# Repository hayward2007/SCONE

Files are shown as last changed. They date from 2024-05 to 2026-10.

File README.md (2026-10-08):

# SCONE

**도움이 필요한 사람에게 직접 찾아가는 로봇을 만들고 싶었습니다.**<br>
**Building a robot that can bring help to the person who needs it.**

Six-legged robot Capable Of rotational motioN · 김형석 / Hyoung-Seok Kim

[한국어](#한국어) · [English](#english) · [Posters & papers](#posters-and-papers) · [Videos](#videos) · [Development archive](#development-archive)

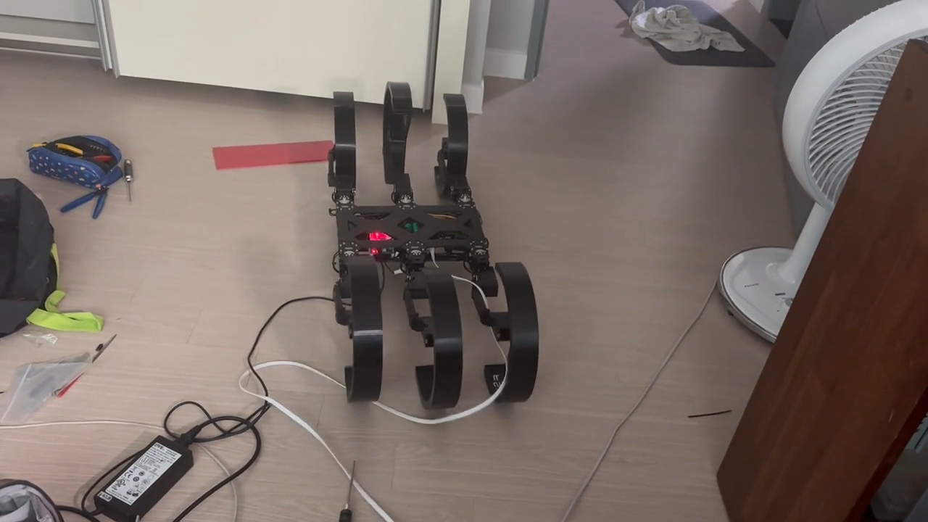
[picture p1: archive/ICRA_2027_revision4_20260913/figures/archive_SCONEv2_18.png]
SCONE v2 실물 로봇 / Physical SCONE v2 prototype


*SCONE v2의 실제 제작·동작 기록에서 가져온 장면입니다. / A frame from the original SCONE v2 hardware footage.*

> **보관된 프로젝트 / Archived project · 2026-10-09**<br>
> 제작 과정, 소스, 포스터, 논문, 실물 영상과 후속 설계를 함께 보존합니다.<br>
> Hardware history, source code, posters, papers, videos and later designs are preserved here.<br>
> [전체 정리 및 복원 안내 / Project closeout and restoration](docs/31-project-archive.md)

## 한국어

### 왜 만들었는가

고등학교에서 동아리를 홍보하던 중 친구가 쓰러진 일이 있었습니다.
그 일을 겪으며, 의식을 잃은 사람을 혼자 힘으로 옮기는 일이 얼마나 어려운지 실감했습니다.
도움이 필요한 사람에게 필요한 장비가 직접 찾아갈 수 있다면 어떨까 하는 생각이 들었습니다.

그 경험이 SCONE을 만들기 시작한 계기였습니다. 사람에게 직접 도달할 수 있는 이동 로봇을 만들고,
그 로봇을 **자동제세동기(AED)를 환자에게 전달하는 로봇으로 응용해 보았습니다.**
그 과정에서 중요하게 생각한 것은 평지에서 움직이는 것뿐 아니라, 실제 이동 경로에서 마주치는
계단과 턱도 통과할 수 있는 구조였습니다.

이 질문은 친환경 배송과 응급 장비 전달이라는 두 응용으로 이어졌습니다.
초기 논문과 포스터에는 배송 로봇의 이동 문제, 제작 과정, 실패와 개선을 정리했고,
포스터의 마지막에는 AED 같은 중요한 물품을 필요한 사람에게 직접 전달하는 방향을 담았습니다.
이 저장소는 그 생각이 실제 로봇, 실험, 설계와 코드로 발전한 기록입니다.

### 어떤 로봇인가

SCONE은 다리 끝에 **C자형 부채꼴 바퀴**를 붙인 6족 로봇입니다.
같은 말단 구조를 회전시키거나 다리 관절을 움직여 걷기, 구르기와 계단 이동을 탐구했습니다.
초기 실물은 3D 프린팅 프레임과 DYNAMIXEL 모터로 제작했고, 이후에는 MuJoCo에서 접촉 기하,
보행 제어와 계단 자세를 비교하며 동작을 분석했습니다.

이 저장소에는 다음 작업이 함께 들어 있습니다.

- **실물 제작:** 초기 평행 링크 구조, 프레임·타이어·모터·전원 개선과 v1/v2 동작 영상.
- **이동 제어:** Walk/Drive/Climb, 교대 삼각보, 연속 굴림과 다리별 굴림·보행 역할 분리.
- **시뮬레이션과 학습:** MuJoCo 모델, 지형 생성, PPO 학습, 다리 상실 대응과 반복 벤치마크.
- **후속 설계:** MARC 계열의 4족 기구, 하우징, 팔, Jetson·U2D2 배치 및 전원 검토.

자료에는 성공한 동작과 함께 전원 부족, 미끄러짐, 모터 과부하, 프레임 문제와 실패한 실험도 남겼습니다.
실물 제작 영상과 후속 시뮬레이션의 정량 실험은 각각의 조건과 근거를 따라 읽을 수 있도록 구분했습니다.

## English

### Why I built it

The idea began when a friend collapsed while I was promoting a club at my high school.
That experience made me realize how difficult it can be for one person to move someone who has lost consciousness.
I began thinking about a robot that could bring essential equipment directly to the person who needed it.

That became the starting point for SCONE. I wanted to build a mobile robot that could reach people,
and I explored **delivering an automated external defibrillator (AED) as an application.**
The mobility problem mattered: reaching a person could mean dealing with stairs and curbs as well as a flat floor.

The project connected that motivation with two applications: environmentally friendly delivery and emergency equipment delivery.
The original papers and poster document the delivery problem, construction, failures and improvements.
The poster also presents bringing vital supplies such as an AED directly to the recipient as a future application.
This repository preserves how that idea developed into hardware, experiments, designs and software.

### What SCONE is

SCONE is a six-legged robot with **C-shaped arc wheels at the ends of its limbs**.
By rotating the terminal frames and articulating the legs, I explored walking, rolling and stair climbing
with the same mechanism. The early hardware used 3D-printed parts and DYNAMIXEL actuators.
Later work used MuJoCo to study contact geometry, gait control and stair postures.

The archive brings together:

- **Hardware development:** the original parallel-link design, frame, tire, actuator and power revisions, and v1/v2 footage.
- **Locomotion:** Walk/Drive/Climb, tripod walking, continuous rolling and per-leg rolling/stepping roles.
- **Simulation and learning:** MuJoCo models, generated terrain, PPO training, leg-loss adaptation and repeated benchmarks.
- **Later designs:** the four-legged MARC mechanism, housing, arm, Jetson/U2D2 integration and power-system review.

The records include successful motions and the problems encountered along the way: insufficient power,
slipping, actuator overload, structural issues and failed trials.
The historical hardware footage and the quantitative simulation studies retain their own experimental context.

## Posters and papers

### 제작 포스터 / Original project poster

실제 제작 사진, v1에서 v2로의 개선, 실험 결과와 AED 전달 응용을 한 장에 담은 포스터입니다.
The original poster brings together hardware photos, the v1-to-v2 improvements, experiments and the AED delivery application.

Eco-friendly delivery, SCONE — original research poster

[원본 포스터 열기 / Open the full-resolution poster](archive/assets/Eco-friendly%20deliver%20SCONE%20Poster.jpg)

### 연구 요약 / Quad chart

연구 질문, 제작 방법, 초기 결과와 개선 방향을 정리한 원본 요약 자료입니다.
The original quad chart summarizes the research question, methods, early results and planned improvements.

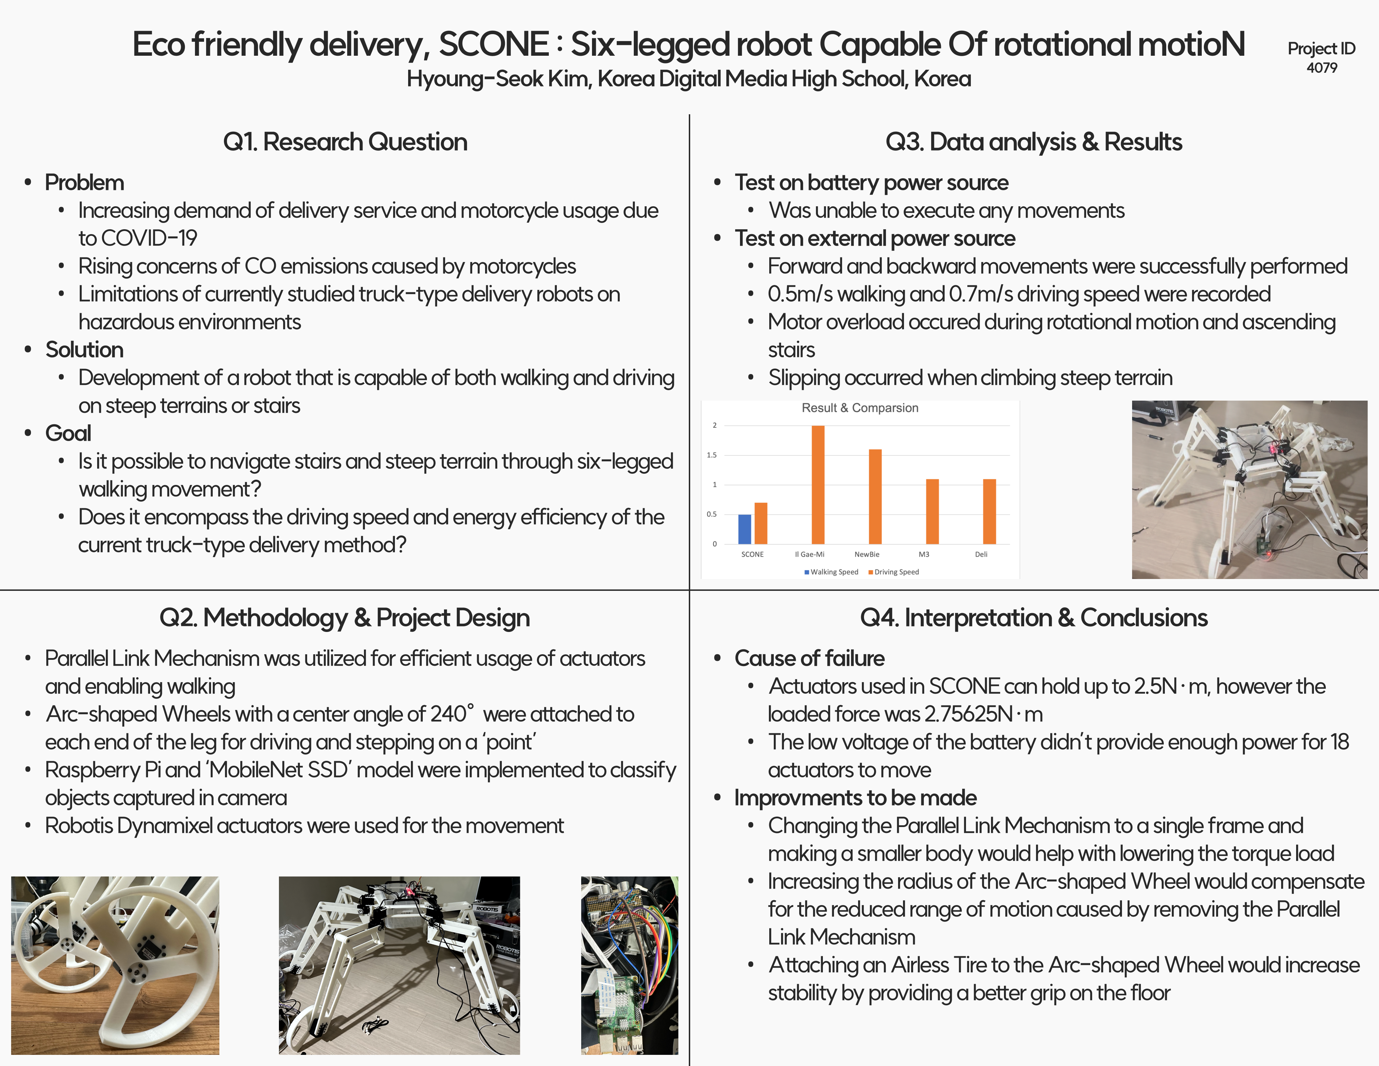
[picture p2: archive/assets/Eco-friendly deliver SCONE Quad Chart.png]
SCONE original research quad chart


[원본 요약 자료 열기 / Open the full-resolution quad chart](archive/assets/Eco-friendly%20deliver%20SCONE%20Quad%20Chart.png)

### 초기 논문과 도면 / Original papers and drawing

| 자료 / Material | 내용 / Contents | 원본 / Original |
| --- | --- | --- |
| **회전운동이 가능한 6족 로봇, 스콘의 개발** | 제21회 KSEF 과학프로젝트대회 국문 논문, 10쪽. 제작 배경과 초기 구조·실험. / Korean paper with construction and early experiments. | [국문 PDF / Korean PDF](archive/papers/대한민국_한국디지털미디어고등학교_김형석_논문.pdf) |
| **Eco-friendly deliver, SCONE** | KSEF 영문 논문, 6쪽. 배송 로봇의 이동 문제와 초기 실물의 성능·한계. / English paper on delivery mobility and the early prototype. | [영문 PDF / English PDF](archive/papers/Eco-friendly%20deliver%20SCONE%20Paper.pdf) |
| **SCONE v2 Arc-Shaped Wheel** | 부채꼴 말단의 치수와 형상을 기록한 원본 제작 도면. / Original dimensioned arc-wheel drawing. | [도면 PDF / Drawing PDF](archive/assets/SCONEv2%20Arc-Shaped%20Wheel.pdf) |

### 후속 이동 연구 / Later locomotion research

**Posture and Contact Geometry in Simple Hybrid Locomotion of an Articulated Arc-Leg Hexapod**

ICRA 2027용으로 준비한 6쪽 연구 원고입니다. 같은 6족 기체에서 평지 이동과 계단 오르기에
필요한 제어를 얼마나 단순화할 수 있는지 살펴봅니다. 원고에는 별도의 MuJoCo 평지 176회,
계단 102회 실험과 접촉 형상·관절 자세·수치 민감도 비교를 담았습니다.

This six-page manuscript was prepared for ICRA 2027. It studies how much control can be simplified
while retaining flat transport and stair ascent on the same hexapod. It reports separate 176-trial flat
and 102-trial stair studies in MuJoCo, including contact geometry, posture and numerical sensitivity.

[연구 원고 PDF / Manuscript PDF](archive/ICRA_2027_submission_20260914/01_UPLOAD/SCONE_ICRA2027_Paper.pdf)
· [한글 검토서 / Korean review](archive/ICRA_2027_revision5_20260913/output/pdf/SCONE_ICRA2027_Review_KO.pdf)
· [LaTeX 원문 / LaTeX source](archive/ICRA_2027_revision5_20260913/paper.tex)
· [실험 근거 / Experiment records](archive/ICRA_2027_revision5_20260913/evidence/)
· [원고와 실험 설명 / Research notes](archive/ICRA_2027_revision5_20260913/README.md)

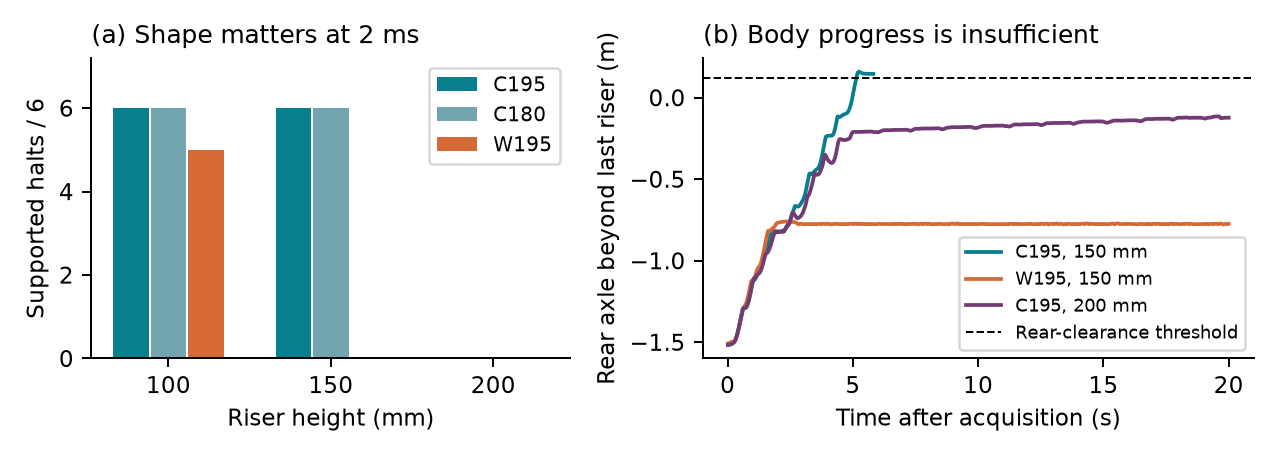
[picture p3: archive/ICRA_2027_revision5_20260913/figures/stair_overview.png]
후속 연구의 계단 시뮬레이션 / Stair simulation from the later research


*MuJoCo 시뮬레이션 그림입니다. 실물 시험 영상은 아래에 따로 보존했습니다. / MuJoCo simulation; original hardware videos are linked below.*

### 원고 이력 / Manuscript history

이전 버전의 한글·영문 원고와 개정 자료도 함께 공개합니다. 위 PDF를 최신 보관 원고로 읽고,
아래 파일은 각 작성 시점의 연구 기록으로 확인할 수 있습니다.
Earlier bilingual drafts and revisions are retained alongside the latest archived manuscript.

| 버전 / Version | 원고 / Manuscript | 관련 자료 / Notes |
| --- | --- | --- |
| 초기 ICRA 작업 원고 / Early ICRA draft | [한국어 / Korean](archive/ICRA/output/SCONE_ICRA_Korean.pdf) · [English](archive/ICRA/output/SCONE_ICRA_English.pdf) | [원문·빌드·설명 / Sources and notes](archive/ICRA/README.md) |
| 2026-09-12 초안 / Initial packet | [English PDF](archive/ICRA_2027_20260912/output/pdf/SCONE_ICRA2027_Manuscript_EN.pdf) | [검토·개정 자료 / Review and revision records](archive/ICRA_2027_20260912/) |
| Revision 2 | [English PDF](archive/ICRA_2027_revision2_20260912/output/pdf/SCONE_ICRA2027_Manuscript_EN.pdf) | [자료 / Packet](archive/ICRA_2027_revision2_20260912/) |
| Revision 3 | [English PDF](archive/ICRA_2027_revision3_20260913/output/pdf/SCONE_ICRA2027_Manuscript_EN.pdf) | [자료 / Packet](archive/ICRA_2027_revision3_20260913/) |
| Revision 4 | [English PDF](archive/ICRA_2027_revision4_20260913/output/pdf/SCONE_ICRA2027_Manuscript_EN.pdf) | [자료 / Packet](archive/ICRA_2027_revision4_20260913/) |
| Revision 5 | [English PDF](archive/ICRA_2027_revision5_20260913/output/pdf/SCONE_ICRA2027_Manuscript_EN.pdf) | [자료 / Packet](archive/ICRA_2027_revision5_20260913/) |

## Videos

### 실물 제작과 이동 / Original hardware demonstrations

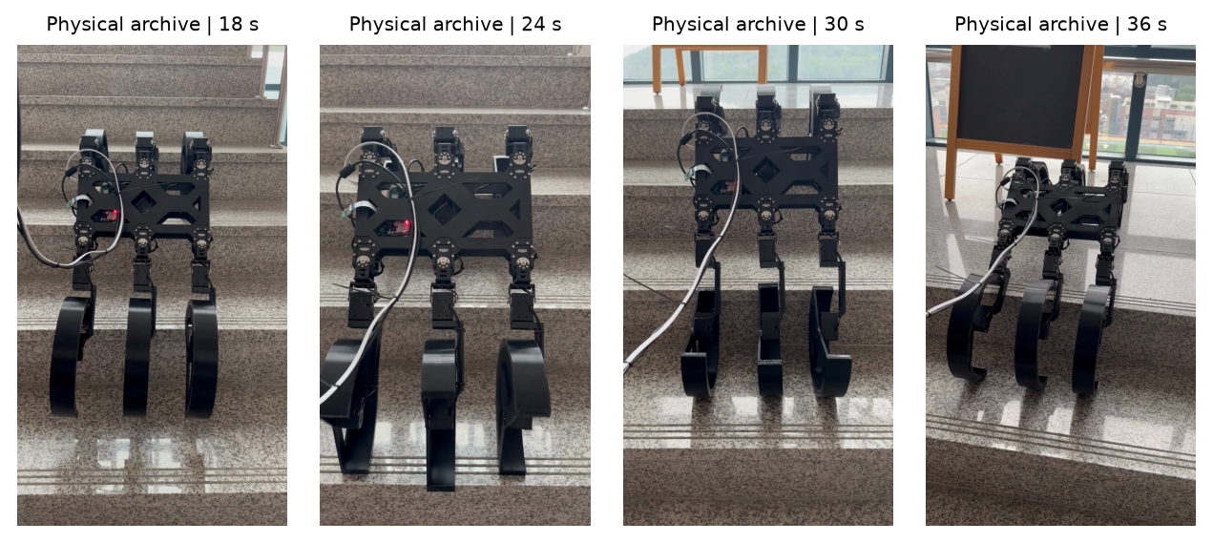
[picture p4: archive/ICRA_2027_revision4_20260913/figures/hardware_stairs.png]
실제 SCONE v2 계단 동작 기록 / Frames from the SCONE v2 physical stair footage


| 영상 / Video | 내용 / Contents |
| --- | --- |
| [SCONE v1](archive/videos/SCONEv1.mp4) | 초기 실물의 동작 기록. / Original prototype footage. |
| [SCONE v2](archive/videos/SCONEv2.mp4) | 개선한 기체의 평지 동작과 자세 전환. / Revised hardware, floor motion and posture changes. |
| [SCONE v2 — stairs](archive/videos/SCONEv2_stairs.mp4) | 실제 계단에서 촬영한 원본 영상. / Original physical stair-climbing footage. |
| [실물 중심 보조 영상 / Hardware-focused companion video](archive/ICRA_2027_submission_20260914/01_UPLOAD/SCONE_ICRA2027_Video.mp4) | v2 실물 영상 두 편 전체와 시뮬레이션 장면을 구분한 편집본, 약 96초. / Full v2 hardware clips followed by labeled simulation segments, about 96 seconds. |

[편집 출처와 구성 / Video sources and edit notes](archive/ICRA_2027_video_revision2_20260920/README_KO.md)
· [원본 실물 영상 폴더 / Hardware video archive](archive/videos/)

### 시뮬레이션 / Simulation demonstrations

| 영상 / Video | 내용 / Contents |
| --- | --- |
| [평지 주기적 이동 / Periodic flat motion](archive/ICRA_2027_revision4_20260913/media/joint_P.mp4) | 후속 평지 제어의 시뮬레이션 재생. / Replay of the later flat controller. |
| [150 mm 계단 / 150 mm stairs](archive/ICRA_2027_revision5_20260913/media/stair_45.mp4) | 계단 통과와 지지 정지 재생. / Stair ascent and supported halt. |
| [같은 계단의 원형 바퀴 비교 / Matched closed-wheel comparison](archive/ICRA_2027_revision5_20260913/media/stair_47.mp4) | 접촉 형상을 바꾼 비교 재생. / Replay with the matched wheel geometry. |
| [200 mm 계단의 실패 사례 / 200 mm stair failure](archive/ICRA_2027_revision5_20260913/media/stair_75.mp4) | 뒷다리 전체 통과를 완료하지 못한 한계도 보존. / Retained example of incomplete rear-leg transfer. |

[추가 시뮬레이션 영상·이미지 / More simulation videos and images](archive/simulation_media/README.md)

## Development archive

SCONE은 고등학교의 초기 제작에서 이동 제어·학습·후속 기구 설계로 이어졌습니다.
MARC는 그 부채꼴 바퀴 원리를 이어가는 계열 이름이며, 4족 설계는 초기 6족 실물과 구분해 보관합니다.

SCONE grew from the high-school prototypes into locomotion control, learning and later mechanical designs.
MARC names the continuing arc-wheel robot family; the later four-legged designs are kept distinct from the original hexapods.

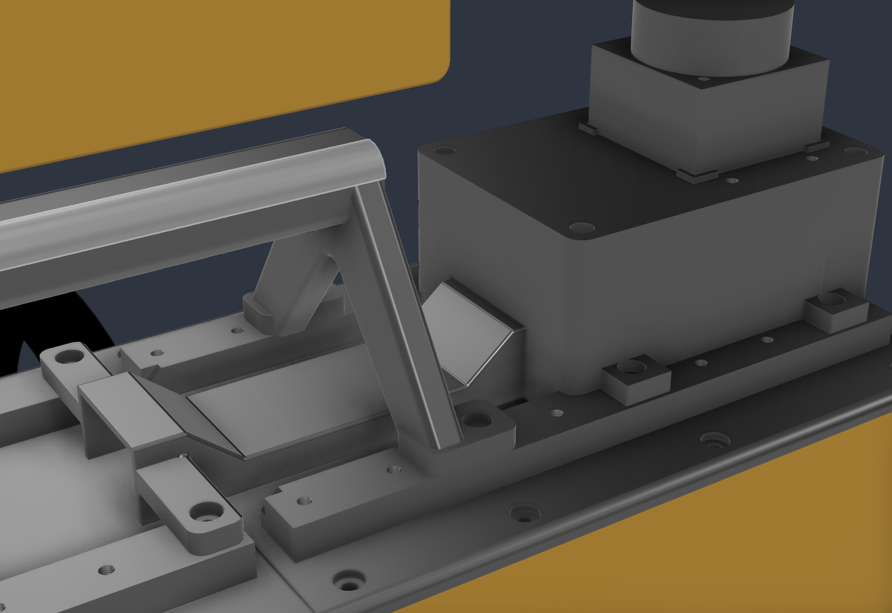
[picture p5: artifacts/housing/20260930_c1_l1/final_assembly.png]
후속 MARC 기구 설계 / Later MARC mechanical design


*후속 설계의 CAD 화면입니다. / CAD view of a later design.*

| 기록 / Record | 보관 위치 / Archive |
| --- | --- |
| 브랜치 정리·이전 시스템 / Branch consolidation and historical systems | [`main` 및 보관 이력 / Main and archived history](archive/branch_history/README.md) |
| 원래 SCONE v2 제어 시스템 / Original SCONE v2 control system | [소스·포스터·논문·압축 영상 / Source, poster, papers and compressed footage](archive/scone_v2/README.md) |
| 이전 역할 분리 실험 / Earlier role-split experiments | [실험 스냅샷과 전체 이력 / Experiment snapshot and complete history](archive/experiments/scone_gait_v2/README.md) |
| 전체 기술·개발 문서 / Technical documentation and development history | [문서 색인 / Documentation index](docs/README.md) |
| 굴림·보행 역할 분리와 두 다리 구동 / Rolling/stepping roles and two-leg rolling | [역할 분리 / Role split](docs/28-scone-gait-v2-role-split-rolling.md) · [두 다리 구동 / Two-leg rolling](docs/29-two-leg-sector-drive.md) |
| MARC 설계 계보와 검증 명세 / MARC lineage and verification plan | [설계 명세 / Design plan](docs/30-scone-v3-design-plan.md) |
| CAD·하우징·팔·전장 / CAD, housing, arm and electronics | [산출물 / Artifacts](artifacts/) |
| 배터리·전원 PCB 검토 / Battery and power-board review | [검토 PDF / Review PDF](output/pdf/MARC_v4_battery_P1_review_20261007.pdf) |
| 실험·소프트웨어 시험 / Benchmarks and software tests | [Benchmarks](benchmark/README.md) · [Tests](tests/) |
| 학습 정책과 별도 개발 상태 / Saved policies and development snapshots | [복원 안내 / Snapshot and checkpoint notes](archive/development_snapshots/20261009/README.md) |
| 전체 보관 범위와 남은 작업 / Complete archive scope and remaining work | [종료 문서 / Closeout guide](docs/31-project-archive.md) |

CAD, 영상과 체크포인트 등 Git LFS 자료를 로컬에서 열려면 복제 후 `git lfs pull`을 실행합니다.
Install Git LFS and run `git lfs pull` after cloning to retrieve the binary originals.
PDF와 MP4는 위 링크에서 열거나 내려받을 수 있습니다.
PDFs and MP4s can be opened or downloaded from the links above.

## Run and develop

<details>
<summary><strong>실행·API·구조·학습 가이드 펼치기 / Expand the runtime, API, architecture and training guide</strong></summary>

The original technical guide is preserved below. For detailed Korean instructions, see the [documentation index](docs/README.md).

SCONE is a six-legged robot project with one high-level control API and two
interchangeable backends: physical DYNAMIXEL hardware and MuJoCo simulation.

## Quick start

Run the launcher on macOS with `mjpython` so the MuJoCo viewer can own the main
thread:

```bash
python -m pip install -r requirements.txt
mjpython SCONE.py
```

The launcher defaults to English. Select Korean with:

```bash
mjpython SCONE.py --language korea
```

`--language english` and `--language korea` keep the same internal menu values,
controller names, checkpoints, and robot commands; only terminal UI text
changes. The selected language continues into simulation pickers, the joystick
dashboard, and the RL launcher.

The launcher searches for a physical controller without changing torque or
position, then displays an English control center by default:

```text
? Choose an activity
❯ Interactive simulation · drive with the terminal joystick
  Automatic stair demo · no manual control
  Hardware control · connected (...) or not detected
  Reinforcement learning · train, inspect, replay
  Rescan hardware
  Quit
```

Use the arrow keys and Enter to choose launcher, profile, terrain, and RL
options. Press Ctrl-C to leave a selection menu safely.

The detailed Korean documentation starts at [`docs/README.md`](docs/README.md),
and the complete learning/checkpoint runbook is in
[`docs/07-running-testing-and-operations.md`](docs/07-running-testing-and-operations.md).
The RL/simulation history is in
[`docs/08-rl-development-log.md`](docs/08-rl-development-log.md), and the latest
hardcoded/model-based gait performance diagnosis and prioritized roadmap are in
[`docs/09-gait-performance-analysis.md`](docs/09-gait-performance-analysis.md).
The complete `tripod-gait`/`scone-gait` algorithm, compatibility, validation,
and tuning guide is in
[`docs/10-tripod-gait-and-scone-gait.md`](docs/10-tripod-gait-and-scone-gait.md).
The arc-wheel hooking equations, historical stair hypotheses, synchronized-phase
controller, and measured simulation results are in
[`docs/11-scone-stair-climbing.md`](docs/11-scone-stair-climbing.md).
The complete diagnosis and measured rework of motor limits, tripod support sag,
continuous distal-frame rotation, and the no-input stair demo are in
[`docs/12-automatic-stair-demo-and-continuous-roll-rework.md`](docs/12-automatic-stair-demo-and-continuous-roll-rework.md).
The implementation and modification entry point for every major feature—from
hardware and gait code to terrain, stair control, RL compatibility, and
validation—is
[`docs/13-feature-implementation-and-modification-guide.md`](docs/13-feature-implementation-and-modification-guide.md).
The current `roll-gait` rename, PPO/hybrid `scone-gait`, Drive-to-Climb stair
preparation, and physical stage-1 register checks are documented in
[`docs/14-roll-gait-and-hybrid-scone-gait.md`](docs/14-roll-gait-and-hybrid-scone-gait.md).

`Automatic stair demo` asks only for `hardcoded`, `improved`, or sequential
`compare`, plus one stair preset. It does not open the terminal joystick.
Both strategies first align the six terminal C-frames to one geometric phase.
`hardcoded` first reproduces Legacy Climb's 270-degree vertical leading
stage-1 pose and then free-runs in velocity mode. `improved` uses a measured
180/184/195-degree brace for 100/150/200 mm risers and keeps one unwrapped phase
target in extended-position mode.

After choosing simulation control, select one locomotion implementation:

- `Legacy mode control`: adapts terminal input to the original blocking
  Walk/Drive/Climb state machine. Press `R` to cycle modes. Walk uses W/S and
  yaw; Drive/Climb use A/D for their left/right motion.
- `tripod-gait`: sends all three axes to the classic alternating-tripod + IK gait;
  the MuJoCo route uses the SCONE-tuned 1.0 Hz, 90/70 mm workspace and 25 mm
  lift without a profile limiter. This avoids the clipped 0.8 Hz path that mixed
  forward/backward contact and accumulated yaw.
- `roll-gait`: preserves the former continuous-rotation controller. It moves
  the upper/stage-1 joints with a full basic gait, adds the stage-2 basic-gait
  angular-rate term to continuous distal-frame rotation, and offsets tripod B
  by 60° so the C-frame openings do not unload together.
- `scone-gait`: requires a PPO checkpoint. Slow translation and in-place yaw
  remain under PPO control; fast translation smoothly changes to a full-body
  point-support tripod whose C-frames accumulate real multi-turn rotation in
  late stance and unloaded swing, then brake before touchdown.
- `scone-stair`: turns SCONE side-on, synchronizes all six terminal frames, and
  completes both Walk→Drive and Drive→Climb preparation before placing leading
  stage-1 IDs 7/9/11 in a rise-dependent brace and advancing one shared
  closed-loop phase. Odd/even MuJoCo axes receive mirrored joint targets that
  represent the same physical C-frame angle. This path is simulation-only.
- `RL control`: asks for a local `runs/**/*.zip` PPO checkpoint, standing pose,
  and residual reference. It runs PPO Walk at 50 Hz and also accepts `R` to
  cycle through legacy Drive/Climb without replacing the shared controller.

Simulation opens a self-centering velocity joystick in the terminal:

```text
W/S       joystick Y (forward/backward)
A/D       joystick X (left/right strafe)
Left/Right arrow  yaw
Space     immediate neutral
R         Walk -> Drive -> Climb -> Walk (Legacy/RL control)
H         return to home pose (Legacy control)
Q         return to the launcher
```

The dashboard displays normalized `x`, `y`, and `yaw` values together with the
scaled body-frame `vx`, `vy`, and `yaw_rate` command. A held key is maintained by
normal keyboard repeat; shortly after release its axis automatically returns to
zero. Multiple live axes are combined, so translation and yaw can be commanded
together.

The MuJoCo window has no SCONE-specific key callback. All joystick keys are read
by the terminal, so robot commands do not alter viewer rendering controls. The
physical-hardware launcher retains the proven discrete W/A/S/D command surface;
the continuous gait is not enabled on real hardware automatically.

## Python API

`import SCONE` is the stable public entry point. Object construction does not
open a serial port and does not start an interactive CLI.

```python
import SCONE
from src.hardware import Controller, discover_hardware

probe = discover_hardware()
if probe.available:
    with SCONE.SCONE(Controller(probe.device_name), profile="sport") as robot:
        robot.forward()
        robot.left()
        robot.change_mode()
```

See `example.py` for a runnable hardware example. A custom backend can be used
by implementing `src.hardware.ControllerProtocol` and passing it to
`SCONE.SCONE`.

## Command flow

```text
terminal key
  -> src.cli normalized x/y/yaw joystick
       -> LegacyVelocityAdapter -> src.main.SCONE old motions
       -> TripodGait / RollGait -> MuJoCoController
       -> PPO + point-support SconeGait supervisor -> SconeWalkEnv
       -> SconeStairClimber -> rolling / tripod-assist -> MuJoCoController
       -> PPO policy -> SconeWalkEnv residual action -> MuJoCoController

no-input automatic demo
  -> HardcodedStairRoller / SconeStairClimber -> MuJoCoController
```

The terminal owns the only keyboard map. Each locomotion implementation consumes
the same body command `[vx, vy, yaw_rate]`; the MuJoCo viewer has no robot key
callback of its own.

## Folder responsibilities

```text
SCONE.py                         stable `import SCONE` facade and CLI launcher
example.py                       minimal API usage example
src/main.py                      high-level robot lifecycle and command API
src/cli.py                       the only interactive key/launcher interpreter
src/hardware/
  actuator_index.py              physical IDs and leg/tripod groups
  actuator_control_table.py      register address + byte width per motor model
  actuator.py                    ID-to-model catalogue and shared constants
  interface.py                   ControllerProtocol backend contract
  controller.py                  physical DYNAMIXEL transport only
  discovery.py                   non-mutating serial/DYNAMIXEL probe
src/locomotion/
  profile.py                     Standard/Sport posture and speed values
  walk.py, drive.py, climb.py    backend-independent motion sequences
  legacy_velocity.py             x/y/yaw adapter for blocking old motions
  tripod_gait.py                 classic alternating-tripod gait + model-based IK
  scone_gait.py                  bounded SCONE sector reference used by RL
  stair_geometry.py              arc-wheel/stair reach, torque, friction, stability checks
  non_rl_walk.py                 compatibility imports for the former name
src/kinematics/
  leg.py                         model-derived FK/Jacobian/numerical IK per leg
  robot.py                       six-leg FK/IK and actuator-order conversion
  types.py                       joint-angle, end-pose, and IK result types
src/simulation/
  core/
    model.py                     MJCF loading, terrain injection, base setup
    controller.py                virtual DYNAMIXEL implementation
    pid.py                       voltage-input DC motor position loop
    cli_bridge.py                one viewer + common terminal CLI integration
    scone_rolling_gait.py        continuous distal-frame velocity gait for MuJoCo
    stair_climber.py             synchronized-phase stair motion for MuJoCo
    stair_demo.py                no-input hardcoded/improved/compare stair viewer
    simulator_cli.py             direct simulation entry point and terrain menu
  stair_benchmark.py             historical + synchronized headless comparison
  terrain/
    types.py                     terrain names and validated parameter types
    presets.py                   explicit stair/slope difficulty dimensions
    generator.py                 rough/stair/ramp/mixed MJCF algorithms
  controller.py, model.py, ...   backward-compatible import shims only
src/rl/
  inquiry.py                     InquirerPy local/SSH training launcher
  joystick_control.py            live PPO policy + x/y/yaw simulation runner
  walk_learn.py                  Gym environment, observations, rewards, PPO CLI
  walk_v2.py                     canonical-frame redesign (82 observations)
  walk_v3.py                     residual walk with no speed limit, free body
                                 height and a locked attitude (76 observations)
  walk_failsafe.py               walking with one or two legs lost: fault-adaptive
                                 wave scaffold, stability first (85 observations)
  remote_watch.py                SSH checkpoint mirroring and local replay
src/assets/                       MJCF and meshes used by simulation/RL
runs/                             generated training/checkpoint data (gitignored)
tests/                            API, actuator-map, and simulation contract tests
```

Dependency direction is one-way: locomotion knows only the controller protocol;
hardware and simulation never own key mappings or gait decisions; reinforcement
learning consumes the simulation backend without being imported by the core API.

## Simulation terrain

Terrain is injected into the robot MJCF at load time from explicit primitive
definitions in `src/simulation/terrain`. No generated terrain is written into
`src/assets`: boxes and ramps need no external mesh, parameters remain easy to
review, and the same generator can produce deterministic or randomized courses.

Available names are `flat`, `uneven`, `stairs-1`, `stairs-2`, `stairs-3`,
`slope-1`, `slope-2`, `slope-3`, and `mixed`. The root launcher displays the
same list when simulation control is selected.

```python
from src.simulation import load_model

model = load_model(terrain="mixed", terrain_seed=42)
```

The three stair presets use fixed per-step rises of 100, 150, and 200 mm.
The 200 mm preset uses 350 mm treads after the former 170--240 mm course was
shown to trap both three-leg banks; the public `TerrainGenerator.add_stairs()`
algorithm also accepts a custom `StairProfile`. Slopes use 8°, 15°, and 25°.
The mixed course contains the
rough patch and all six difficulty variants with equal gaps, and generates
matching descents so every section returns to the base floor.

See `src/simulation/terrain/README.md` for the complete dimensions.

## Actuator metadata

The physical map is centralized in `Actuator.Index`:

```text
IDs 1..6    upper/body stage     MX-28AT
IDs 7..12   middle/leg stage     XM430-W350-T
IDs 13..18  distal wheel stage   XM430-W210-T
```

For leg `n`, `Actuator.Index.for_leg(n)` returns `(n, n+6, n+12)`. All models
use 4096 position units per revolution. Register access in the hardware
controller goes through the model control tables. Multi-motor target poses use
DYNAMIXEL GroupSyncWrite, while MuJoCo implements the same batch API locally.

## Kinematics

Kinematics load `src/assets/model.xml` directly. Joint locations, axes,
left/right axis reversal, body transforms, and tire frames therefore come from
the same MJCF used by simulation rather than separately hard-coded link lengths.

Angles are radians around raw position 2048: `0 rad = 180 motor degrees`. The
default end effector is the origin of each `TIRE_1` through `TIRE_6` body.

```python
import numpy as np
import SCONE

# One leg: motor degrees -> FK, then position IK.
leg = SCONE.LegKinematics(leg=1)
pose = leg.forward_motor_degrees([135, 170, 195], frame="body")
result = leg.ik(
    pose.position,
    initial_angles=SCONE.JointAngles.from_motor_degrees([140, 168, 192]),
)
print(result.converged, result.angles.as_motor_degrees())

# Whole robot: input/output actuator order is motor ID 1..18.
kinematics = SCONE.RobotKinematics()
motor_degrees = np.array(
    [135, 135, 180, 180, 225, 225] + [170] * 6 + [195] * 6
)
poses = kinematics.forward_motor_degrees(motor_degrees)
targets = np.stack([poses[leg].position for leg in range(1, 7)])
results = kinematics.ik(
    targets,
    initial_angles=np.radians(motor_degrees - 180.0),
)
solved_motor_degrees = kinematics.results_as_motor_degrees(results)
```

IK solves the 3D position with a damped-least-squares MuJoCo Jacobian. Three
joints cannot independently constrain both position and tire orientation, so
orientation is returned by FK but is not an IK target. Use current measured
joint angles as the IK initial value to select the nearest solution branch.

For a calibrated tire/contact point instead of the tire-frame origin, pass its
local coordinate with `LegKinematics(..., end_effector_point=[x, y, z])` or use
the `end_effector_points` mapping on `RobotKinematics`.

## `tripod-gait` and `scone-gait`

`TripodGait` is a continuous, model-based gait engine separate from the legacy
discrete `Walk` motions. It accepts body-frame `[vx, vy, yaw_rate]`, generates
alternating tripod foot trajectories, solves all six legs through the MJCF IK,
and produces one batch of 18 motor positions.

```python
import SCONE

gait = SCONE.TripodGait(controller, profile="sport")

# Call at 50 Hz. Units: m/s, m/s, rad/s.
sample = gait.update(
    SCONE.VelocityCommand(vx=0.04, vy=0.00, yaw_rate=0.20),
    dt=0.02,
    send=True,
)
print(sample.stance_legs, sample.failed_legs)
```

The support tripods are `(1, 4, 5)` and `(2, 3, 6)`. During stance, a foot
moves opposite the requested body twist; during swing, minimum-jerk horizontal
interpolation and a zero-touchdown-velocity lift arc return it to the front.
Yaw uses `omega × r` at each nominal foot position, so turning is not a shared
sideways offset. Command filtering, velocity/stride limits, and an all-or-none
IK send guard are enabled by default in `GaitConfig`.

The shared physical default keeps a fixed 0.8 Hz cadence. Interactive MuJoCo
`tripod-gait` uses 1.0 Hz, a 90/70 mm fore-aft/lateral workspace, 25 mm lift,
an unlimited DYNAMIXEL profile, and a simulation-only 2x middle-joint hold.
Motor voltage, torque, and PID limits remain active; only the lagging profile
ramp is removed.
The residual-RL reference deliberately remains at its checkpoint-compatible
0.7 Hz and 60/50 mm configuration. An IK-failed frame can shrink its foot
offsets up to four times before it is rejected.
Legacy PPO checkpoints were trained with the simulation controller's unlimited
profile velocity/acceleration, so RL reset preserves that actuator behavior.
Physical model-based gait benchmarks still apply the selected motion profile;
do not compare or resume policies across those dynamics without retraining.

`SconeGait` keeps a bounded 18-position mode for training-reference
compatibility. Interactive `scone-gait` enables its multi-turn mode: the first
55% of stance is a fixed point, late stance starts propulsion, unloaded swing
continues the same rotation direction, and the last 30% of swing brakes before
touchdown. The checkpoint owns slow translation and in-place yaw; this
full-body walking plus accumulated C-frame rotation owns fast motion.

`RollGait` is the separate simulation-only continuous-rotation controller.
It reuses the mesh tangent/IK solution for all 18 joints: IDs 1..12 receive the
basic position targets, while IDs 13..18 stay in velocity mode and receive
continuous roll plus the time derivative of their bounded basic-gait offset.

```python
scone_gait = SCONE.SconeGait(controller, profile="standard")
sample = scone_gait.update(
    SCONE.VelocityCommand(vx=0.04, vy=0.02, yaw_rate=0.15),
    dt=0.02,
    send=True,
)
```

The gait does not treat the centre of `TIRE_n` as a foot. At startup it loads
the collision mesh from `model.xml`, applies the selected profile pose, and
uses the centre of each TPU sector tip's lowest 0.1 mm patch as a fixed local
support point. This avoids anchoring IK to one lateral edge of the 44 mm-wide
frame. Supplying
`end_effector_points` overrides this automatic selection with measured points.

Before physical use, call `gait.reset_from_controller()` to centre the stroke
on the measured 18 positions, calibrate each tire's actual support point via
`end_effector_points`, and tune the conservative defaults in MuJoCo. The module
does not automatically enable torque or initialize hardware.

The gait architecture is based on the public
[Lynxmotion Phoenix implementation](https://github.com/KurtE/Phantom_Phoenix)
by Jeroen Janssen, Kurt Eckhardt, and Kåre Halvorsen (Zenta), together with the
[Phoenix PEP description](https://wiki.lynxmotion.com/info/wiki/lynxmotion/view/ses-v1/ses-v1-robots/ses-v1-3-4-dof-hexapods/phoenix-excel-kinematic-seq-01/).
Its phase-offset, stance-translation, swing-lift, and IK structure was adapted
to SCONE's `model.xml`; the trajectory is not a byte-for-byte port of its
discrete Arduino servo loop.

## Reinforcement-learning launcher

Install the RL dependencies and open the interactive launcher:

```bash
python -m pip install -r requirements.txt
python -m src.rl
```

The same menu is available as `Reinforcement learning` from `mjpython SCONE.py`. It
asks for the residual reference (`tripod-gait`, experimental `scone-gait`, or
legacy `hardcoded`), curriculum, terrain,
standing pose, timestep count, checkpoint interval, and local/SSH destination.
For SSH training it probes physical/logical CPU cores, available memory, and
load before asking for `num_envs`. The editable recommendation reserves one
physical core, 2 GiB for the OS/PPO parent, and estimates 768 MiB per MuJoCo
environment. Runs with more than one environment use `SubprocVecEnv`, so this is
real process parallelism rather than sequential interleaving.

For a remote run, the launcher can synchronize the current local source first
(excluding `.git`, virtual environments, `runs`, and archives), then starts the
trainer with `nohup`. If the remote RL packages are missing, it can create a
Python 3.12 project-local `.venv` and install the unified `requirements.txt`
automatically before creating the run directory. A pre-existing virtualenv
using another Python version is renamed to `.venv.python-old_<timestamp>` rather
than deleted. Remote artifacts remain on the training machine at:

```text
~/Developer/SCONE/runs/<run-name>/
  train.log
  train.pid
  checkpoints/scone_walk_<steps>_steps.zip
  final_model.zip
```

The launcher can run a local environment/reward smoke test, show the remote PID
and recent log output, atomically download and ZIP-validate the newest
checkpoint/final model into the matching local `runs/<run-name>/` directory,
continuously mirror checkpoints while a local MuJoCo viewer is open, or replay
any downloaded `.zip` policy.

If reward or observation semantics change and a run must restart from zero,
choose `Archive and reset a remote run`. The launcher refuses to touch a running
trainer without a separate confirmation and requires the exact run name. It
then moves the complete remote run (checkpoints, final model, PID, and log) to
`runs/.reset_backup/<run-name>_<timestamp>` instead of permanently deleting it.
The original run name is then free for a clean training run.

## Direct commands

```bash
# Old and model-based gait joystick control
mjpython -m src.simulation --control old --profile standard
mjpython -m src.simulation --control tripod-gait --profile standard --terrain mixed
mjpython -m src.simulation --control roll-gait --profile standard --terrain flat
mjpython -m src.simulation --control scone-stair --profile standard --terrain stairs-3

# No-input stair viewers (compare opens hardcoded, then improved)
mjpython -m src.simulation --demo compare --terrain stairs-2
mjpython -m src.simulation --demo improved --terrain stairs-3

# RL joystick control with a downloaded/trained checkpoint
mjpython -m src.simulation --control rl \
  --checkpoint runs/remote_watch/scone_walk_700000_steps.zip \
  --rl-reference-motion tripod-gait \
  --terrain flat

# Hybrid scone-gait (standing pose must match this checkpoint)
mjpython -m src.simulation --control scone-gait \
  --checkpoint runs/walk_full_standard/checkpoints/scone_walk_15410928_steps.zip \
  --rl-reference-motion hardcoded \
  --rl-standing-pose-degrees \
    135 135 180 180 225 225 240 240 240 240 240 240 255 255 255 255 255 255

# RL environment smoke check
PYTHONPATH=. python -m src.rl.walk_learn --reference-motion scone-gait check \
  --steps 5 --curriculum easy

# PPO training
PYTHONPATH=. python -m src.rl.walk_learn --reference-motion tripod-gait train \
  --curriculum easy --timesteps 1000000 --num-envs 4

# walk_v3: one scaffold rollout, then training. The reference tracks the
# command instead of saturating, body height is free and attitude is the hard
# constraint (docs/22-walk-v3-residual-design.md)
PYTHONPATH=. python -m src.rl.walk_v3 --stance standard check --command 0.30 0 0
PYTHONPATH=. python -m src.rl.walk_v3 --stance standard train \
  --curriculum easy --timesteps 20000000 --num-envs 8

# walk_failsafe: the same robot with a leg gone. The scaffold reschedules
# itself around the working legs and shifts the body back inside the support
# polygon (docs/27-failsafe-ppo-and-leg-loss.md)
PYTHONPATH=. python -m src.rl.walk_failsafe check --failed-legs 5 --command 0.06 0 0
PYTHONPATH=. python -m src.rl.walk_failsafe train \
  --curriculum easy --timesteps 20000000 --num-envs 8

# Unit and integration-contract tests
python -m unittest discover -s tests -v

# Re-run every stair hypothesis and the H3 tuning sweep as JSON Lines
python -m src.simulation.stair_benchmark --all --tuning
```

The locomotion reward configuration is defined by `RewardConfig` in
`src/rl/walk_learn.py`; reward calculation and per-term logging
are implemented in `SconeWalkEnv` in the same file. `src/rl/walk_v3.py` carries
its own `RewardConfig`/`SconeWalkEnvV3` pair: a one-sided speed reward with no
ceiling, no height term at all, and attitude enforced by cost and termination.
`src/rl/walk_failsafe.py` inverts that shape: command tracking is the only way
to score, everything else is a bounded deficit, and the configuration refuses
any weighting whose penalties out-budget the reward.

</details>

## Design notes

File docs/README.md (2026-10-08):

# SCONE 프로젝트 문서

**2026-10-09 프로젝트 아카이브.** 최종 정리·자료 색인·검증 상태·복원 절차는
[프로젝트 종료 및 아카이브](31-project-archive.md)를 먼저 확인한다.
최종 브랜치는 `main` 하나이며, [이전 시스템·브랜치 이력](../archive/branch_history/README.md)은 폴더와 태그로 보존했다.
아래 문서의 작성 당시 상태와 수치는 역사 기록으로 보존한다.

이 문서는 2026-09-02 기준 SCONE 저장소 전체를 설명한다. 현재 RL·시뮬레이션 코드, `runs/`의 학습 산출물 구조, `archive/`의 논문·도면·구형 코드도 함께 조사했다. 코드와 과거 문서의 설명이 다를 때는 현재 코드와 테스트를 우선한다.

## 문서 읽는 순서

1. [프로젝트 개요](01-project-overview.md) — 목표, 주요 기능, 현재 범위
2. [기능과 기술](02-features-and-technologies.md) — 구현 기능과 사용 기술
3. [아키텍처와 데이터 흐름](03-architecture-and-data-flow.md) — 실제 장치·시뮬레이션·RL의 연결
4. [문제와 해결 과정](04-problems-and-solutions.md) — 원인, 진단, 적용한 해결책, 남은 위험
5. [파일과 폴더 지도](05-file-and-folder-map.md) — 저장소의 파일별 역할
6. [변수와 상수 사전](variables/README.md) — 영역별 변수·상수·상태 필드
7. [보상함수 수정 가이드](06-reward-function-guide.md) — 현재 수식, 수정 절차, 검증법
8. [실행·학습·운영·검증](07-running-testing-and-operations.md) — 설치, CLI, 테스트, 체크포인트 운영
9. [RL·시뮬레이션 개발 기록](08-rl-development-log.md) — 초기 설계부터 실패·수정·검증까지의 이력
10. [보행 성능 분석과 개선 로드맵](09-gait-performance-analysis.md) — 하드코드/Non-RL/RL 수치 비교와 우선순위
11. [`tripod-gait`와 `scone-gait` 상세 가이드](10-tripod-gait-and-scone-gait.md) — 이름·수식·IK·부채꼴 rolling/creep·CLI/RL·검증·튜닝 전체 설명
12. [SCONE 부채꼴 후킹과 계단 알고리즘](11-scone-stair-climbing.md) — 후킹 기하·토크·마찰·안정 조건, 여섯 프레임 공통 위상, 옛 앞 1단 270° 재현과 partial-brace sweep·최종 수치
13. [자동 계단 데모와 연속 회전형 `roll-gait`의 역사](12-automatic-stair-demo-and-continuous-roll-rework.md) — 입력 없는 synchronized open/closed-loop 비교, 세 다리 지지 처짐, motor profile·보폭 sweep, C자 말단 연속 회전 phase 가설
14. [기능 구현 및 코드 수정 가이드](13-feature-implementation-and-modification-guide.md) — launcher·하드웨어·Legacy·FK/IK·MuJoCo·terrain·두 gait·계단·RL·원격 학습의 구현 흐름, 수정 절차, 호환 경계와 검증 기준
15. [`roll-gait` 분리와 PPO/점접지 하이브리드 `scone-gait`](14-roll-gait-and-hybrid-scone-gait.md) — 현재 이름, 저속/yaw PPO와 고속 multi-turn 전환식, point-support/누적회전 공식, 계단 Drive→Climb 준비, stage-1 live read-back, 15.4M checkpoint 검증
16. [보행·계단·PPO 통합 활동 기록](15-complete-development-activity-log.md) — 전체 요청·가설·실행·채택/기각·수치·코드 위치·검증·남은 한계를 한 문서에서 추적
17. [ICRA 시뮬레이션 벤치마크 구현과 실행 기록](16-icra-simulation-benchmark-implementation-and-results.md) — 평지·계단 A/B/C, 강건성·모드 전환 벤치마크, 실제 실행 수치, 통계·검증·논문 사용 조건
18. [구형 PPO 진단과 개선 계획](17-ppo-diagnosis-and-fix-plan.md) — `walk_learn` 70차원 정책의 역사적 진단과 V2 이전 개선 근거
19. [액추에이터 모델·좌표계·PPO V2 설계](18-actuator-model-and-frame-convention.md) — DC motor/armature 검증, 정규 좌표계, `walk_v2` 초기 설계와 CLI
20. [공개된 다이나믹셀 MuJoCo 모델과 설정 대조](19-actuator-settings-vs-published-models.md) — OP3·Open Duck 모델과 SCONE dcmotor/armature를 같은 벤치에서 비교한 결과
21. [백래시 적용과 다이나믹셀 패키지 분리](20-backlash-and-dynamixel-package.md) — 직렬 유격 모델, 단위 버그, 민감도 측정과 독립 패키지 구조
22. [`walk_v2` PPO 실제 학습 분석과 2차 재설계](21-walk-v2-ppo-training-analysis.md) — 35.4M checkpoint 진단, 행동 포화·누적 motor randomization 원인, 정지 보상 제거, 학습/재생 randomization 분리, primitive curriculum, bounded PPO·fixed-command best-model과 재학습 gate
23. [`walk_v3` 설계와 보정](22-walk-v3-residual-design.md) — v1 residual 구조 복귀, 명령에서 역산하는 기준 모션 보정표, 단측 속도 보상(속도 상한 없음), 높이 자유·자세 고정 제약, 76차원 관측과 체크포인트 라우팅
24. [`walk_v3` 신설 작업 기록](23-walk-v3-session-record.md) — 원격 재생 오류의 원인과 수정, v3 요구사항 확인, 측정 기반 보정 과정, 발견한 두 결함, 승격 규칙 수정, 검증 결과와 다음 단계
25. [리팩토링 진단과 방향](24-refactoring-assessment.md) — 학습기 3종의 인프라 중복(및 그것이 만든 실제 버그), 패키지 순환 의존, 죽은 shim, 사유 속성 접근, 우선순위와 ICRA 동결 기준 순서, 건드리면 안 되는 것
26. [ICRA 제출 실험 계획](25-icra-submission-plan.md) — matched 프로토콜이 동작하지 않는 원인과 수정, 주장↔증거 대응표, E0~E7 실험과 소요 시간, RL·실물 포함 결정, 표·그림 목록과 동결 체크리스트
27. [계단·하이브리드 이동 이론](26-stair-and-hybrid-locomotion-theory.md) — 위상 고정 heave 측정, 계단 5단계 모델과 `h>R_o`에서 관절이 필수인 이유, slip ratio로 정식화한 "미끄러지듯 이동", 회전율 제어 법칙 제안과 반증 가능한 예측
28. [결손 대응 PPO와 다리 상실 모델링](27-failsafe-ppo-and-leg-loss.md) — 교대 삼각보가 다리 하나에 무너지는 이유, `detached`/`limp` 두 결손 모델과 런타임 변이, 웨이브 스케줄·몸체 시프트 유도와 측정, 관절공간 스캐폴드 보정표, 하나만 얻고 여럿을 잃는 보상 예산
29. [`scone-gait-v2` 역할 분리 굴림](28-scone-gait-v2-role-split-rolling.md) — 실제 부채꼴 기하, 조향과 굴림/보행 역할 분리, 속도·slip 분석
30. [두 다리 부채꼴 구동](29-two-leg-sector-drive.md) — 다리별 접지·지지·추진 회계, 앞/뒤 쌍 구동 및 동일 예산 대조군
31. [MARC v4 설계·검증 실행 명세](30-scone-v3-design-plan.md) — SCONE/MARC 계보, 4족 D0/D1/RELEASE 관문과 검증 입력
32. [프로젝트 종료 및 아카이브](31-project-archive.md) — 최종 보관 범위, 자료 색인, 남은 한계, 검증 기록과 복원 절차

## 문서 범위와 표기

- **현재 코드**: `src/`, 루트 API, 테스트가 정의하는 실제 동작이다.
- **역사 자료**: `archive/`, [`08-rl-development-log.md`](08-rl-development-log.md), 구형 영상과 논문은 설계 배경을 설명하지만 현재 API를 정의하지 않는다.
- **생성 파일**: `runs/`, `tmp/`, 캐시, 논문 빌드 결과는 프로그램 산출물이므로 파일 형식과 보존 목적을 묶어서 설명한다.
- **변수 사전**: 모듈 상수, 열거형, 데이터 클래스 필드, 장기 상태, 외부 동작에 영향을 주는 매개변수를 개별적으로 기록한다. `i`, `item`, `error`처럼 의미가 자명하고 일회성인 반복·예외 지역변수는 해당 함수의 흐름으로 묶어 설명한다.
- 단위는 별도 표기가 없으면 각 코드의 원 단위를 따른다. Dynamixel 위치는 raw 값 또는 degree, MuJoCo 관절은 radian, 시간은 second이다.

## 현재 상태에서 특히 주의할 점

- 구형 70차원 정책의 기준은 `src/rl/walk_learn.py`, 82차원은 `src/rl/walk_v2.py`, 76차원은 `src/rl/walk_v3.py`, 85차원은 `src/rl/walk_failsafe.py`다. 네 환경의 checkpoint는 서로 호환되지 않으며, 관측 폭이 학습기를 식별한다(`policy_compat.task_for_observation_shape`). V2의 학습 상태는 [`21-walk-v2-ppo-training-analysis.md`](21-walk-v2-ppo-training-analysis.md), V3의 설계·측정 근거는 [`22-walk-v3-residual-design.md`](22-walk-v3-residual-design.md), 다리를 잃은 상태의 보행은 [`27-failsafe-ppo-and-leg-loss.md`](27-failsafe-ppo-and-leg-loss.md)를 우선한다.
- 현재 시뮬레이터는 액추에이터 이름(`A01_` … `A18_`)을 통해 관절을 찾는다. 과거의 고정 mirror-pair 재배열 방식은 현재 구현이 아니다.
- 실물 장치 코드는 보존되어 있으며 시뮬레이션의 좌우 축 보정은 MJCF 모델에서 처리한다.
- RL 정책은 시뮬레이션에서 학습·재생한다. 실제 로봇에 바로 배포하는 상태 추정·안전 계층은 아직 완성된 기능이 아니다.
- Residual RL 기준 모션은 새 실행에서 `tripod-gait`가 기본값이며 `scone-gait`는 실험 선택지다. 기존 작업 기록에는 `hardcoded` 또는 `non_rl`이 저장돼 있을 수 있으므로 재개 전에 설정을 확인한다.
- 두 gait를 수정하거나 새 checkpoint를 학습하기 전에는 [`10-tripod-gait-and-scone-gait.md`](10-tripod-gait-and-scone-gait.md)의 reference 호환성, 동역학 검증값, 실물 진입 조건을 먼저 확인한다.
- `scone-stair`는 현재 MuJoCo 전용이다. 실물 계단 적용 전에는 [`11-scone-stair-climbing.md`](11-scone-stair-climbing.md)의 마찰·모터 전류·nosing·지지다각형 실측 항목을 먼저 검증한다.
- lower velocity-mode 자유 회전은 `roll-gait`다. 현재 `scone-gait`는 저속/제자리 yaw PPO와 고속 점접지 tripod+위상 동기 multi-turn 말단 회전을 합치는 checkpoint 필수 supervisor다. [`14-roll-gait-and-hybrid-scone-gait.md`](14-roll-gait-and-hybrid-scone-gait.md)를 우선한다.
- 계단 준비는 실제 상태기와 같은 Walk→Drive→Climb 순서를 완료한 뒤 공통 위상 제어로 넘어간다. 물리 Drive 진입 시 stage-1 mode/profile/goal/present register를 read-back한다. MuJoCo의 Drive 1단 댐핑 2배는 여전히 시뮬레이션 전용이다.
- `benchmark/` 결과는 현재 MuJoCo와 controller 구현의 개발 증거다. dirty worktree의 단일 명목 실행을 논문 최종 성능으로 사용하지 말고, [벤치마크 실행 기록](16-icra-simulation-benchmark-implementation-and-results.md)의 보정·반복·실물 교차 검증 조건을 따른다.

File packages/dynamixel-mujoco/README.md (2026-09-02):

# dynamixel-mujoco

Model a DYNAMIXEL actuator in MuJoCo without double-counting gearbox loss.

Small, dependency-light, and verified by simulation rather than by assertion:
the test suite loads the emitted MJCF and checks it reproduces the ROBOTIS
e-Manual.

```bash
pip install -e .
dynamixel-mujoco-bench          # datasheet, damping and backlash checks
```

## The rule

**Encode the torque-speed line exactly once.**

The e-Manual stall torque and no-load speed are measured at the **output shaft
of the assembled actuator**, so gearbox and motor loss already lives inside
them. A `dcmotor` built from that pair reaches zero net torque exactly at the
rated no-load speed:

```
actuator            stall [N m]          no-load [rad/s]
                sheet        sim      sheet        sim     err
MX-28AT         2.500      2.500      5.760      5.760  -0.00%
XM430-W350-T    4.100      4.100      4.817      4.817  -0.00%
XM430-W210-T    3.000      3.000      8.063      8.063  -0.00%
```

Adding `damping` or `frictionloss` on top double-counts the loss. In one
measured case a plausible-looking `frictionloss` of 0.06-0.09 N m cost 3.0-3.7%
of no-load speed across the three actuators.

Models built on a `position` actuator must do the opposite, because a position
source has no back-EMF term: their `damping` *is* the torque-speed line. Two
independent examples, both of which reproduce the servo's rated no-load speed
to within a few percent:

| model | arithmetic | result | rated |
| --- | --- | ---: | ---: |
| MuJoCo Menagerie `robotis_op3` (XM430-W350) | `(5 - 0.03) / 1.084` | 4.59 rad/s | 4.82 |
| Open Duck Mini v2 (Feetech STS3215) | `(3.23 - 0.068) / 0.56` | 5.65 rad/s | ~5.5 |

Neither convention is wrong. Mixing them is.

## What the e-Manual does not contain

**Inertia.** A torque-speed pair is a steady-state characteristic, so reflected
rotor inertia has to be supplied separately, and leaving it out is the largest
single sim-to-real error in a geared servo model. At 193-353:1 it is 0.2x to
2.5x the link inertia of a small leg.

```python
from dynamixel_mujoco import spec
item = spec("XM430-W350-T")
item.armature                      # 0.01749 kg m^2  = J_rotor * N^2
item.mechanical_time_constant      # 0.0206 s, invariant under gearing
```

ROBOTIS does not publish rotor inertia, so `DEFAULT_ROTOR_INERTIA` is an
estimate chosen to put `tau_m` in the 10-25 ms band such motors occupy.
**Identify it per actuator** by fitting a no-load step response to
`w(t) = w_inf (1 - exp(-t/tau_m))`; that needs no knowledge of `J_rotor`.

Published armature values for the same XM430-W350 span 0.01749 (this package)
to 0.045 (Menagerie). Treat that 2.6x as the uncertainty band and check that
your conclusions survive it.

### Adding armature invalidates your PD gains

`kd` tuned for critical damping at the link inertia is no longer critical once
armature is added. Measured step overshoot on a 20-degree step:

| armature | kd | overshoot |
| --- | ---: | ---: |
| ignored | `2*sqrt(kp*J_link)` | up to 13.6% |
| included | `2*sqrt(kp*(J_link + armature))` | 0.0% |

```python
item.critical_damping(kp=9.40, link_inertia=0.01668)
```

## Backlash

The e-Manual publishes it (20 arcmin on the MX-28AT, 15 on the XM430) and it is
not negligible: at a 0.12 m contact radius, 15 arcmin is 0.5 mm of contact
position. Model it as a limited free joint in series with the driven joint;
MuJoCo composes the joints of one body in order, so a second hinge on the same
axis makes the body angle the sum.

```python
import xml.etree.ElementTree as ET
from dynamixel_mujoco import add_backlash, by_pattern

root = ET.parse("robot.xml").getroot()
add_backlash(root, by_pattern(
    (r"M0[1-6]_", "MX-28AT"),
    (r"M(0[7-9]|1[0-2])_", "XM430-W350-T"),
    (r"M1[3-8]_", "XM430-W210-T"),
))
```

Two things that bite:

* **Units.** MuJoCo defaults to *degrees* when `<compiler angle=...>` is absent,
  so a radian range emitted into such a model shrinks the dead band 57-fold.
  `add_backlash` reads the setting; `backlash_joint` takes it explicitly. There
  is a regression test for this.
* **Stiffness.** MuJoCo's default joint limit is soft enough that a working
  torque pushes several times past the stop. The defaults here hold the stop to
  within 4% of the limit up to stall torque.

A real X-series encoder sits on the output shaft, so **whatever reads joint
position must sum the driven angle and the play**, otherwise the controller
sees a joint that is stiffer than the hardware.

## Catalog

| actuator | 12 V stall | no-load | gear | backlash | armature | tau_m |
| --- | ---: | ---: | ---: | ---: | ---: | ---: |
| MX-28AT | 2.5 N m | 55 rpm | 193:1 | 20' | 0.00521 | 12 ms |
| XM430-W350-T | 4.1 N m | 46 rpm | 353.5:1 | 15' | 0.01749 | 21 ms |
| XM430-W210-T | 3.0 N m | 77 rpm | 212.6:1 | 15' | 0.00633 | 17 ms |

Add an entry only from the e-Manual itself; every other field is derived.

## Not modelled

Continuous-torque derating (`saturation` is the *instantaneous* stall limit and
a real unit overheats within seconds of holding it), thermal effects, supply
sag, bus latency, and backdrive resistance. With no Coulomb term a de-energized
joint here is frictionless. If you measure a friction split and want to add
`frictionloss`, you must raise the `nominal` no-load speed to the motor-side
value in the same edit:

```
w_nominal = w_sheet / (1 - frictionloss / stall_torque)
```

## Origin

Extracted from the [SCONE](https://github.com/hayward2007/SCONE) hexapod
project, where the double-counting mistake was made, measured, and corrected.

## Licence

MIT.

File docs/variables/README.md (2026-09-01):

# 변수와 상수 사전

이 디렉터리는 “값을 어디서 바꾸면 무엇이 달라지는가”를 빠르게 찾기 위한 사전이다.

`tripod-gait`와 `scone-gait`의 수식·처리 순서·설정 간 관계는
[`10-tripod-gait-and-scone-gait.md`](../10-tripod-gait-and-scone-gait.md)를
먼저 읽고, 이 디렉터리에서는 개별 필드와 상태값을 찾는다.
계단 후킹 수식과 `scone-stair` 상태 전환의 근거는
[`11-scone-stair-climbing.md`](../11-scone-stair-climbing.md)를 먼저 읽는다.
비-RL 연속 회전 설정, support 처짐 보정과 자동 데모 변수의 채택 근거는
[`12-automatic-stair-demo-and-continuous-roll-rework.md`](../12-automatic-stair-demo-and-continuous-roll-rework.md)를 따른다.

## 문서 구성

- [API·CLI·하드웨어·locomotion](01-api-hardware-locomotion.md)
- [기구학·시뮬레이션·지형](02-kinematics-simulation-terrain.md)
- [강화학습](03-reinforcement-learning.md)
- [테스트·자산·아카이브](04-tests-assets-archive.md)

## 포함 기준

개별 행으로 기록하는 대상:

- 모듈 또는 클래스 상수
- `Enum`/`IntEnum` 값
- 데이터 클래스의 모든 필드
- 인스턴스에 유지되는 상태 변수
- 단위, 좌표계, 안전 범위, 외부 I/O를 바꾸는 함수 매개변수
- 의미가 이름만으로 드러나지 않는 계산 중간값

묶어서 기록하는 대상:

- 단순 반복자의 `i`, `item`, `motor_id`, `leg`
- 예외 객체 `error`
- return 직전 한 번만 사용되는 `result`, `value`
- 동일한 의미의 dictionary comprehension 지역변수

이런 짧은 지역변수도 무시한 것은 아니다. 각 파일의 “주요 지역변수” 행에서 실행 흐름 단위로 묶었다.

## 공통 규칙

| 이름/형태 | 공통 의미 |
|---|---|
| `motor_id` | Dynamixel ID 1–18. `leg`, `leg+6`, `leg+12`가 한 다리의 세 관절 |
| `leg` | 다리 번호 1–6 |
| `raw` | Dynamixel 위치 단위. 4096 count/revolution, 중심 2048 |
| `degrees` | motor position을 degree로 표현. 중립 관절각은 일반적으로 180° 기준 |
| `angles`, `qpos` | MuJoCo 관절 radian |
| `dof`, `qvel` | MuJoCo generalized velocity 주소/값 |
| `vx`, `vy` | body frame 선속도. `+vx` 전진, 모델의 `+vy` 왼쪽 |
| `yaw_rate` | body z축 회전속도. 양수는 왼쪽/counter-clockwise |
| `phase` | gait cycle 위치, 범위 `[0, 1)` |
| `dt` | 한 물리 또는 제어 step의 시간 |
| `seed` | 재현 가능한 난수 지형/학습을 위한 seed |
| leading `_` | 외부 public API가 아닌 내부 상태/도우미 |

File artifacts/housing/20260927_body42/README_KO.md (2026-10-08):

# 본체 42 / MX28AT 체결 개선

기준: 2026-09-27 Fusion에서 열려 있던 MARC Housing PLA R09 Assembled v6의 본체42, 본체12 및 사용자 다리 자세.

## 설계

- 네 MX28 모터의 위치, 각도 및 다리 형상 유지.
- 본체12의 16개 구멍 중심을 그대로 사용. 체결 높이 z=3.5 mm 유지.
- 5 mm 체결 받침: z=-1.5~3.5 mm.
- M2.5 통과 구멍 Ø2.81 mm, 카운터보어 Ø5.0 mm × 깊이 1.5 mm.
- 카운터보어 바닥부터 모터 접촉면까지 잔여 두께 3.5 mm.
- 받침 아래 3 mm 국부 리브 및 아래쪽 Ø6.4 mm 공구 접근 통로 16개.
- 본체42와 모터의 기존 겹침을 없애는 국부 포켓.
- 외부 상단 모서리 R6 및 경사 모서리 R3. 기존 긴 면과 경사면을 유지하는 절제된 SPOT 참고 외형.

## 측정 및 검증

- 외곽 치수: 420.123 × 172.658 × 200.000 mm, 원본과 동일.
- 본체 재료 부피: 1054.802 → 1023.965 cm³ (-2.92%).
- 원래 내부 빈 공간: 약 7495.226 cm³. 원본 내부 평면의 단면적을 구간별 적분한 값.
- 추가 재료: 10.522 cm³. 추가 재료 전부가 원래 내부 공간을 차지한다고 가정해도 기존 공간의 99.8596% 이상 보존.
- 16개 체결부의 Ø2.81~Ø5.0 환형 영역에서 높이 3.5 mm 전체가 채워지는지 BRep 교집합으로 검증: 전부 통과.
- 나사 통과 영역 및 아래쪽 나사머리/공구 통로: 본체와 겹침 없음.
- 현재 자세의 가시 다리 솔리드 104개와 본체의 교집합: 겹침 없음.
- 원본에 기록한 모든 occurrence 변환행렬과 최종 조립본 비교: 차이 없음.
- 최종 본체: 닫힌 솔리드 1개, 연결된 덩어리 1개.

## 체결 및 검증 범위

카운터보어 깊이는 요청대로 1.5 mm이다. 나사머리 높이가 1.5 mm보다 크면 받침 밑면보다 돌출한다. 완전 매립을 원하면 머리 높이 1.5 mm 이하이고 외경이 5 mm 홈에 맞는 M2.5 나사를 선택해야 한다. 이 설계에는 돌출 나사머리 및 드라이버가 지나갈 하부 통로가 있다.

나사 길이는 3.5 mm 잔여 두께에 실제 모터 나사산 물림 길이를 더해 선정한다. 실물의 나사산 깊이, 케이블 커넥터 접근, 출력 공차, 체결 강도 및 피로수명은 검증하지 않았다. 현재 결과는 CAD 형상·체결 치수 검증이다. 전체 관절 조합 및 다리 간 간섭을 보증하지 않는다.

## 파일

- SCONE_Body42_MX28_Assembly.f3d: 기존 부품을 포함한 최종 조립본. 원본 본체들은 숨김 참조로 남음.
- SCONE_Body42_MX28_Body.f3d: 개선 본체 단품.
- SCONE_Body42_MX28.step: 개선 본체 단품 STEP.
- SCONE_Body42_MX28.stl: 개선 본체 단품, mm 기준 STL.
- validation.json: 치수·부피·자세·현재 간섭 확인 수치.
- SOURCE_UNMODIFIED_v6.f3d: 최초 원본 보관본. 최초 읽은 미확정 자세는 inventory.json에도 별도 기록.
- SOURCE_POSE_CAPTURED.f3d: 원본 사용자 자세를 Capture Position으로 명시 보존한 보관본. 원본 형상 변경 없음.

## 참고

- Boston Dynamics Spot 공식 제품 페이지: https://bostondynamics.com/products/spot/
- ROBOTIS MX-28 공식 매뉴얼 및 도면 링크: https://emanual.robotis.com/docs/en/dxl/mx/mx-28/

체결 기준 좌표는 웹상의 다른 CAD 모델이 아닌 현재 Fusion 본체12에서 직접 읽었다.

## 가동 공간 추가 검사

각 다리의 MX28 수직축을 현재 자세 기준으로 0~355°까지 5° 간격으로 독립 회전시켰다. 다른 관절 각도는 최초 사용자 자세에 고정했으며, 실제 Fusion 부품을 움직이지 않고 임시 BRep 복사본으로 비교했다. 이는 허용 관절 범위를 지정하거나 360° 전체가 사용 가능하다는 뜻이 아니다.

| 다리 | 검사 자세 수 | 원래 본체에서 간섭 없던 자세 | 새로 막힌 자세 |
|---|---:|---:|---:|
| LEG 1:1 | 72 | 36 | 0 |
| LEG 1(미러):1 | 72 | 24 | 0 |
| LEG 1:5 | 72 | 37 | 0 |
| LEG 1(미러):2 | 72 | 35 | 0 |

총 288개 표본에서 원래 간섭 없던 132개 자세에 새 간섭이 생기지 않았다. 5° 사이의 연속 구간이나 여러 관절의 동시 조합은 검증하지 않았다. 상세 수치는 motion_validation.json 참조.

## 내보내기 확인

단품 STEP/F3D는 솔리드 1개, 연결 덩어리 1개, 면 311개로 내보냈다. STL은 삼각형 18,524개이며, 각 모서리가 두 삼각형에 공유되는 닫힌 매니폴드 메시다. 메시 부피 1023.976 cm³는 BRep 부피와 약 0.0011% 차이다.

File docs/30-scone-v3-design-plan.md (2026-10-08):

# MARC v4 설계·검증 실행 명세 rev.4

개정일: 2026-09-09 · 대상: **실물 기구 MARC v4**

**명칭.** 이 기체를 한 줄로 쓰면 **부채꼴(호) 모양 바퀴로 굴러가면서 걷고 계단을 오르는 다족 로봇**이다.
그 한 줄을 그대로 줄인 것이 이름이다.

**MARC = Multi-legged Arc-wheel Rolling Climber** (확정).

| 글자 | 단어 | 담는 것 |
|---|---|---|
| M | Multi-legged | 다족. 개수를 말하지 않으므로 6족 v1~v3과 4족 v4를 함께 덮는다 |
| A | Arc-wheel | 부채꼴(호) 모양 바퀴 — 이 기체의 핵심 기구 |
| R | Rolling | 주행 (굴림) |
| C | Climber | 계단 이동 |

출발점은 "Multi-legged robot driven by ARC-shaped wheel (or frame)"이었고, 남는 R·C에 주행과
계단을 넣어 네 글자를 모두 뜻이 있게 만들었다. 함께 검토한 ACRA·ARCRA는 쓰지 않는다.
ARCRA는 R이 겹쳐 읽기 불편하고 ACRA는 다른 기관 약어와 겹친다.

**계보.** MARC는 기존 SCONE 전체를 포함하는 계열 이름이다. 다리 수가 6에서 4로 바뀌어도 부채꼴
바퀴로 주행·보행·계단 이동을 하는 원리는 같으므로 세대를 끊지 않고 이어간다.

| 기존 명칭 | 새 명칭 | 내용 |
|---|---|---|
| SCONE v1 | MARC v1 | 6족 최초 기체. 부채꼴 회전축이 다리 중심과 어긋남 |
| SCONE v2 | MARC v2 | 6족. 축 정렬 수정, ㄷ자 개단면 프레임 (파손·흔들림 발생) |
| SCONE v3 (rev.1~3) | MARC v3 | 6족 설계안. CAD 미생성, 문서 단계에서 종료 |
| — | **MARC v4** | **4족. 본 문서의 대상** |

v3는 문서만 있고 실물이 없으므로 v4는 v2 실물과 v3 설계 결정을 함께 승계한다. 저장소 경로
`~/Developer/SCONE`, 기존 파일 이름, MuJoCo 자산 이름처럼 이미 기록으로 남은 식별자는 이번
개정에서 바꾸지 않는다. 개명 적용 범위는 §19.3에 적는다.

이 문서는 다른 에이전트가 작업 순서, 형상 정의, 입력 자료, 합격 기준과 실패 처리를 임의로 정하지
않고 진행하기 위한 명세다. **현재 완료 상태는 설계 문서 개정이며, CAD 생성·구조 해석·실물 제작이
완료된 상태가 아니다.** 미확인 부품 치수나 성능을 가짜 확정값으로 채우지 않는다.

- **D0: 검증용 디지털 후보** — 아래에 정의한 형상과 좌표로 바로 구현한다. 질량·간섭·접지 가정을 검증하는 모델이며 출력용 부품이 아니다.
- **D1: 제작 후보** — 실제 부품 도면·체결·출력 조건을 반영해 제작 검증을 받는 모델이다. D0를 이름만 바꿔 D1로 취급하지 않는다.
- **RELEASE: 제작 확정** — §15의 제작 관문이 모두 통과한 리비전에만 부여한다.

§10의 JSON은 입력 수치의 원천, §11은 좌표와 관절의 원천, §14는 실행 순서, §15는 판정 규칙이다.
다른 표의 반올림 수치를 다시 입력하지 않는다. 여기서 정한 D0 기본 선택은 이번 개정의 **검증을 위한
설계 결정**이며 최적해나 실측값이 아니다.

관련 문서: [기존 프로젝트 문서 색인](/Users/hayward_kim/Developer/SCONE/docs/README.md),
[rev.2 전체 검토](/Users/hayward_kim/Developer/SCONE/docs/reviews/2026-09-09-scone-v3-rev2-review.md),
[rev.3 독립 검증](/Users/hayward_kim/Developer/SCONE/docs/reviews/2026-09-09-scone-v3-rev3-verification.md).
검토 보고서의 원문 줄 번호는 각각 rev.2 / rev.3 기준이다.

## 0. 시작 지침과 현재 판정

### 0.1 다음 에이전트가 먼저 할 일

1. 현재 Git 상태와 이 문서의 SHA-256을 기록한다. 기존 변경을 보존한다.
2. §10 JSON을 추출하고 §16의 독립 계산 예제를 실행한다. 이 단계에는 Fusion이나 하드웨어가 필요 없다.
3. §17의 입력 목록을 만들고 실제 파일·도면·측정값이 있는 항목만 채운다. 나머지는 `null`과 근거 부족 사유를 기록한다.
4. §14의 B00부터 의존 순서대로 구현한다. 표에 있는 후속 스크립트는 **현재 존재하는 도구가 아니라 작성할 산출물**이다.
5. Fusion 접속이 가능하면 새 문서 `MARC-PARAM-D0`에만 생성한다. 기존 `SCONEv3 v8`과 v2 모델은 참조용으로 보존한다.
6. 관문 결과와 다음 실행 가능한 작업을 남긴다. 막힌 작업이 있으면 의존하지 않는 계산·도면 확보·문서화를 계속한다.

### 0.2 상태 용어

| 상태 | 의미 | 사용 규칙 |
|---|---|---|
| `PASS` | 지정된 방법과 허용치로 검증 완료 | 증거 파일·입력 해시·실행 버전 필요 |
| `FAIL` | 자료는 있으나 허용치 위반 | 해당 모델의 후속 승격 중지, 실패 자세/부품 기록 |
| `BLOCKED` | 필요한 도면·측정·환경이 없음 | 필요한 입력 ID와 확보 방법 기록; 0이나 추정값으로 대체 금지 |
| `NOT_RUN` | 입력은 있으나 아직 검사하지 않음 | 성공으로 집계 금지 |
| `CANDIDATE` | 검증을 위해 선택한 기본값 | 모델 생성에 사용 가능, 실물 성능 주장에 사용 불가 |
| `REFERENCE` | 이전 버전의 비교 자료 | 현재 모델의 합격 근거로 승계 금지 |

### 0.3 6족에서 4족으로 바꾼 근거

다리 2개를 빼도 **v3 개선의 대부분이 그대로 살아남는다.** 다리 수와 무관한 항목이기 때문이다.

| v3에서 확정한 개선 | 4족에서 |
|---|---|
| 나선 로브 | 그대로 (heave 효과에 대한 설명은 §2.3에서 정정) |
| ㄷ자 → 폐단면 박스 | 그대로 |
| 립 + 방사 리브 | 그대로 (하중이 줄어 안전율만 상승) |
| 부채꼴 양단 지지 클레비스 | 그대로 |
| 볼트 보스 + 황동 인서트 | 그대로 |
| 센서·전원·PCB 통합 | 그대로 |
| 파라미터화·관문 체계 | 그대로 |
| **다리 피치 130 → 175** | **불필요.** 중간 다리가 없어 조향 간섭 제약이 사라진다 |
| **스핀각 자세 최적화 `alpha_park`** | **필요성 감소.** 질량이 27% 줄어 토크 여유가 생긴다 |

4족 전환으로 얻는 것과 잃는 것 (근거는 §6~§8):

| 항목 | 6족 v3 | 4족 v4 |
|---|---:|---:|
| 질량 | 4.945 kg | **3.615 kg** |
| 모터 | 18개 | **12개** |
| 설계 토크 (기준 자세, 3점) | 98% stall | **72%** |
| 설계 토크 (개 자세, 3점) | 53% | **39%** |
| 굴림 속도 | 0.64~0.97 m/s | 0.63~0.95 m/s |
| 보행 속도 (개 자세 ±15°) | 0.146 m/s | 동일 (트롯도 사이클당 2단계) |
| 계단 걸기 토크 (h=120) | 1.98 N·m | **1.48 N·m** |
| 굴림 중 상하동요 | 위상 최적화 미검토 | **0.00 mm** (대각 위상 180°) |
| 굴림 중 몸 기울기 (피치/롤) | 0.12° / 0.16° | 2.29° / 3.32° |
| 다리 하나 들었을 때 정적 마진 | 86.6 mm | 0 mm (yaw 고정) → **111.0 mm** (지지 다리 yaw 재배치) |

**잃는 것은 굴림 중 몸 기울기 하나뿐이다.** 굴림할 때 피치 2.29°, 롤 3.32° 범위로 몸이 기운다.
6족(0.12°/0.16°)보다 크다. 대신 대각선 두 짝을 180° 어긋나게 굴리면 **몸 높이는 전혀 위아래로
움직이지 않고**(상하동요 0.00 mm) 항상 3개 이상이 땅에 닿는다. 계산 근거는 §7.4에 있다.

**다리를 들 때 정적 마진 0 mm는 다리를 그대로 둔 경우다.** 남은 세 다리의 조향각을 다시
배치하면 마진이 **111.0 mm**까지 나온다(§7.3). 그러므로 4족에서도 정적 크롤이 성립하며 트롯은
속도를 위한 선택지다. 이는 계산 결과이며 실제 제어 성능은 I07/I09로 확인한다.

### 0.4 유지하는 방향과 철회한 결론

유지: 구조재 PLA, 타이어 TPU 95A, 폐단면 링크, 림 양측 립, 방사 리브, 부채꼴 양단 지지,
파라미터화, 4S 배터리와 12V/5V 강압, 센서·배선·교체 경로를 포함한 통합 설계.

철회 (rev.2 → rev.3에서 철회한 것을 승계): `alpha=-25.5°`에서 정지 토크 52%, 확정 안전율 4.63/18,
실물 변형 3.69→0.15mm, v3 실물 heave 14mm, 회전당 전진 481mm, 확정 총질량 4.569kg.

**rev.3에서 추가로 철회하는 것:**
- **"부채꼴 4개로는 최소 2점 접지"** — 틀렸다. 몸체가 기울면 항상 3점이다. 위상이 정하는 것은
  접지 개수가 아니라 기울기 크기다. 그래서 **접지호를 270°로 키우자는 rev.3 검토 제안도 무효**다.
- **"조향축 스윙반경 182.5mm 때문에 전방 굴림이 불가능"** — 틀렸다. 진행 방향은 다리가 뻗는
  방향이며 조향 없이 굴러간다. 이 결론은 "전방 = 몸통 장축"이라는 잘못된 전제에서 나왔다.
- **"role-split 보행이 필수"** — v2의 부채꼴 장착 헤딩이 다리마다 달라서 필요했던 우회책이다.
  v3/v4는 네 부채꼴이 모두 같은 방향이므로 전부 동시에 굴린다.

**현재 판정: D0 구현을 진행한다. 전체 기체 제작 치수 확정은 보류한다.**

## 1. 기준선과 근거의 등급

### 1.1 이전 기체 비교값

| 항목 | 기존 기록 (v2, 6족) | 근거의 한계 |
|---|---:|---|
| 타이어 외반경 / 판 외반경 / 두께 | 122.5 / 112.5 / 10mm | v2 자산 기준; v4 최종 프로파일은 별도 생성 |
| 부채꼴 축방향 폭 | 44mm | D0 폭 20mm와 구분 |
| 접지호 / 개구각 | 225° / 135° | 로브 없는 v2 형상 |
| 부채꼴 / 타이어 질량 | 117.4 / 99.8g | 해당 모델·기록의 값; 새 출력물 실측값 아님 |
| 부채꼴+타이어 스핀 관성 | 2.02e-3kg·m² | 비교 시 부품 범위·축·기준점 일치 필요 |
| 모델 총질량 | 4.161kg | 신규 전장 포함 여부가 다른 BOM과 직접 원인 비교 금지 |
| 다리 수 / 배치 | 6족, 종방향 피치 130mm | v4는 4족. 보행 자산(삼각보·role-split) 승계 불가 |
| 모터 | MX-28AT / XM430-W350-T / XM430-W210-T 각 6개 | v4는 각 4개. 실제 ID·펌웨어는 §17 I01로 확인 |

기존 보행 속도는 명령값·순간 속도·에피소드 평균·순변위 속도를 구분한다. v2 정책이나 보행기의
측정치를 v4 성능으로 옮겨 적지 않는다. **6족 삼각보 기반 보행기(`articulated-walk`,
`role-split-scone`, `rear-pair-roll` 등)는 v4에 그대로 적용할 수 없다.** 4족 트롯/크롤로
새로 작성한다.

### 1.2 저장된 Fusion 자료의 올바른 사용

[프레임 추출](/Users/hayward_kim/Developer/SCONE/tmp/v3review/frame_dump.txt), [축 추출](/Users/hayward_kim/Developer/SCONE/tmp/v3review/axis_dump.txt)은 저장 당시 스냅샷이다. 파일이 다른 환경에 없으면 선택적 참고자료로 처리한다. D0 생성의 필수 입력은 아니다.

- `wall_est=2V/A`로 얻은 1.21/1.24/4.84mm는 **등가 두께 추정**이다. 실제 최소 벽 두께는 솔리드 단면에서 측정한다.
- `fill=18.8%`는 CAD 체적/바운딩박스 비율이다. 슬라이서 infill 설정이 아니다.
- 스케치 중심 y=-149/-150과 조향축 y=-130의 차이는 완성 부채꼴 중면 편심을 입증하지 않는다. 압출 방향과 깊이까지 확인한다.
- 조인트 원점은 동일 회전축을 따라 이동해도 같은 축을 표현할 수 있다. 원점 y값의 일치로 동축도를 판정하지 않는다.
- 기본 강철 재질과 스터디·중복 솔리드가 섞인 root 질량 약 950kg는 로봇 질량이 아니다. §12의 부품 목록으로 집계한다.
- 기존 파손 원인은 파단 위치, 출력 방향, 체결 토크, 하중 기록 없이 단정하지 않는다. 폐단면·양단 지지는 개선 후보로 검증한다.

## 2. 접지 프로파일과 접촉 계산

### 2.1 프로파일 좌표의 유일한 정의

부채꼴 자체 좌표를 `(u,v,w)`로 두고 판은 u–w 평면, 축방향은 v다. 각도 `chi=0`은 +u, 양의 chi는 +u에서 +w로 향한다. **개구는 -u 방향**이며, 각도는 `[-157.5°, +157.5°]`의 재료 구간으로 저장한다. 전역 방향은 §11의 변환으로만 정한다.

```text
chi_tread_end = th_tread/2
chi_material_end = chi_tread_end + d_lobe
rho_t(chi) = R_tread                                      if abs(chi) <= chi_tread_end
rho_t(chi) = R_tread - k_ramp*(abs(chi)-chi_tread_end)      그 밖의 재료 구간
k_ramp = (R_tread-r_lobe_tip)/d_lobe                      [mm/deg]
rho_s(chi) = rho_t(chi)-t_tire                            PLA 외곽
rho_r(chi) = rho_s(chi)-t_rim                             림 내곽
rho_l(chi) = rho_r(chi)-h_lip                             립 내곽
point(r,chi,v) = (r*cos(chi), v, r*sin(chi))
```

기본값에서 타이어 팁/PLA 팁/림 내곽 팁/립 내곽 팁은 각각 **112.5/102.5/99.5/87.5mm**다. 로브에서도 림 두께 3mm와 립 반경 깊이 12mm가 유지된다. 이는 **반경 방향 두께 정의**이며 곡선 법선 방향 등두께와는 다르다. 법선 최소 두께는 최종 형상 검사에 포함한다.

### 2.2 D0 형상 생성 규칙

D0는 불명확한 스플라인·팁 필렛·허니컴을 사용하지 않는다.

1. chi를 시작점부터 끝점까지 `profile_step_deg=0.5` 간격으로 샘플링한다. 양 끝과 ±112.5° 경계를 반드시 포함한다.
2. 각 반경 곡선을 동일 chi 배열의 점으로 만든다. 인접점은 직선으로 잇는다. 폐곡선은 외곽을 정방향, 내곽을 역방향으로 연결한다.
3. 이 다각형을 §3의 v 구간으로 압출한다. 자체 교차, 음수 면적, 0 두께, 실패한 boolean이 하나라도 있으면 B03 실패다.
4. D0에서 `nose_fillet_mm=0`, 웹 포켓 제거율 0, 링크 경량화 홀 제거율 0으로 고정한다. rev.2의 R12 필렛·72% 포켓·25% 경량화는 아직 검증되지 않은 후속 후보다.
5. 최종 D1에서 필렛/포켓을 추가하면 별도 후보 ID를 만들고 프로파일·질량·강성·간섭 검사를 모두 다시 수행한다. 생성 실패 시 필렛 반경을 몰래 줄이거나 형상을 자동 치유해 통과시키지 않는다.

이 선택은 제작 완성도를 주장하기 위한 단순화가 아니라, 같은 수학 형상이 CAD와 계산에 들어가도록 만드는 재현 가능한 기준이다.

### 2.3 지지점과 heave 계산

지면 법선 `n`을 위쪽 단위벡터로 두고, 현재 부채꼴 자세로 변환한 모든 표면점 `r_k(q)`에 대해 계산한다.

```text
h(q,n) = -min_k dot(n, r_k(q))
contact_candidates = { k : dot(n,r_k) - min_j dot(n,r_j) <= support_tol_mm }
p_contact = p_axle + r_k(q)                              접촉 후보별 저장
heave = max_q h - min_q h
```

D0의 평면 프로파일 검사는 chi 0.5°/회전 q 0.5°로 시작하고 둘 다 절반 간격으로 반복한다. heave 변화 <0.05mm이면 수치 수렴으로 판정한다. 접점이 여러 개인 경우 첫 점 하나를 임의 선택하지 않고 모두 반환한다. 실제 접촉 패치와 반력은 이후 강체/접촉 해석에서 결정한다.

필렛 전 연속 프로파일의 회귀 기준은 heave **33.2477mm**, 팁 사이 현 길이 **136.9713mm**다. 이 값은 실물 진동이나 계단 성능의 합격값이 아니다. `r_nose=12mm` 적용 후에도 같다고 가정하지 않는다.

### 2.35 개구각의 결정과 heave에 대한 정정

**정정.** rev.4까지 "나선 로브가 heave를 75.6mm에서 18.56mm로 줄였다"고 썼는데 이는 틀렸다.
heave는 로브의 유무가 아니라 **개구각과 팁 반경**으로 정해진다.

```text
heave = R_tread - r_lobe_tip * cos(개구각/2)
```

같은 개구각이면 램프(로브)가 있는 쪽이 팁 반경이 작아 heave가 오히려 커진다. 확인값:

| 형상 | 개구각 | heave |
|---|---:|---:|
| 로브 45°, 팁 112.5 | 45° | 18.56 mm |
| 램프 없음, 팁 122.5 | 45° | **9.32 mm** |
| v2 (램프 없음) | 135° | 75.62 mm |

75.6 → 18.56은 개구각을 135°에서 45°로 줄인 효과였다. **로브의 실제 효용은 heave 감소가 아니라
① 접지 모서리 충격 완화 ② 계단 걸이용 뾰족한 팁 두 가지다.** 이 두 가지 때문에 로브 45°는 유지한다.

**개구각을 75°로 정한 근거.** rev.4의 45°는 재료가 315°를 덮어 부채꼴이라기보다 노치 낸 바퀴였다.
heave 최소화만 목적함수로 두고 개구각에 하한을 걸지 않은 결과다. 제약을 명시하면 다음과 같다.

1. **접지호 >= 180°** (하드). 이 조건에서만 §7.4의 대각짝 위상이 몸통 상하동요를 정확히 0으로 만든다.
   로브 45°를 유지하면 개구각 상한은 `360 - 180 - 90 = 90°`다.
2. **굴림 중 몸통 기울기**. 기울기는 heave에 비례한다. 피치 `atan(heave/465)`, 롤 `atan(heave/320)`.
3. **목 너비** `2*r_lobe_tip*sin(개구각/2)` — 계단 모서리를 물 수 있는 입 크기.

| 개구각 | 접지호 | heave | 피치 | 롤 | 목 너비 | 스핀 관성비 |
|---:|---:|---:|---:|---:|---:|---:|
| 45° (rev.4) | 225° | 18.56 | 2.29° | 3.32° | 86.1 | 1.000 |
| 60° | 210° | 25.07 | 3.09° | 4.48° | 112.5 | 0.950 |
| **75° (채택)** | **195°** | **33.25** | **4.09°** | **5.93°** | **136.97** | **0.900** |
| 90° (상한) | 180° | 42.95 | 5.28° | 7.64° | 159.1 | 0.851 |

75°를 채택했다. 목 너비가 1.6배가 되고 스핀축 관성이 10% 줄어 §15의 관성 목표 초과가 해소된다.
굴림 기울기는 q1으로 상쇄할 수 있으나 공짜가 아니다: 상쇄에 필요한 β 스윕은 개구각 45°에서 ±15.9°,
75°에서 ±28.5°, 90°에서 ±36.8°다.

### 2.4 이동거리와 계단 치수

- `2πR×195/360=416.916mm`의 이름은 **일정 반경 접지호 길이**다. (개구각 75° 채택 전에는 225°/481.056mm였다.)
- 완전 1회전의 이상적 무미끄럼 이동거리는 모든 접지 상태를 포함해 계산한다. 지지함수 적분의 기준값은 약 739.54mm/rev이며, 이 또한 실물 주행 예측값은 아니다.
- 실물/시뮬레이션 이동거리는 몸체 위치 차이, 속도 적분, 접촉 미끄럼을 함께 기록한다.
- throat 80mm, 팁 반경 감소 8mm, 계단 높이 200mm는 기존 계획에서 계승한 **후보 목표**다. 실제 계단 디딤판·코 반경·마찰·접근 자세는 I09에 별도로 필요하다.
- 순수 기하 heave에 v2 실측/기하 비율 0.767을 곱하는 예측은 사용하지 않는다.

## 3. 부채꼴 구조와 하중

### 3.1 D0 PLA 형상

모든 아래 영역은 동일 프로파일로 생성하고 union한다. v=0은 부채꼴 중면이다.

| 부분 | u–w 영역 | v 압출 구간 mm |
|---|---|---|
| 림 | `rho_r(chi) <= r <= rho_s(chi)` | `[-b_sector/2,+b_sector/2]` |
| 립 두 개 | `rho_l(chi) <= r <= rho_r(chi)` | `[-b_sector/2,-b_sector/2+t_lip]`, `[b_sector/2-t_lip,b_sector/2]` |
| 웹 | `r_hub <= r <= rho_l(chi)` | `[-t_web/2,+t_web/2]` |
| 허브 | 중심 원판 `r <= r_hub` 전체 360° | `[-hub_boss_h/2,+hub_boss_h/2]`, `hub_boss_h=20` |
| 리브 7개 | 아래 방사 스트립을 PLA 외곽 내부로 clip | `[-b_sector/2+t_lip,+b_sector/2-t_lip]` |

리브 중심각은 **`[-150,-100,-50,0,50,100,150]deg`**로 고정한다. rev.2의 ‘7개·45° 등간격·끝점 근처’ 혼용을 제거했다. 각 리브는 해당 각도의 방향을 길이축으로 한 폭 `t_rib`의 직선 스트립이며, 반경 `r_hub-1mm`부터 `R_tread`까지 만든 뒤 PLA 외곽으로 clip한다. 허브와 1mm 겹쳐 union한다. 이 규칙으로 허브–웹–립–림의 연결을 검사한다. 리브 개수를 바꾸면 각도 목록도 명시적으로 새로 작성해야 한다.

**허브는 더 이상 무공이 아니다.** §4.2에서 실측한 혼 인터페이스로 아래를 생성한다. 축방향 로컬 +Z가
모터 쪽, -Z가 베어링 쪽이다.

| 순서 | 형상 | 치수 | z 구간 (허브 중심 0) |
|---|---|---|---|
| 1 | 혼 스피곳 자리 | Ø22.4 | +10 .. +8.5 |
| 2 | 샤프트·중앙나사 릴리프 | Ø9.0 | +10 .. +6 |
| 3 | M2 인서트 파일럿 8개 | Ø3.2, **PCD 16.0**, 45° 등간격 | +8.5 .. +2.5 |
| 4 | 베어링 시트 | Ø19.0 H7 | −10 .. −5 |
| 5 | 스터브 릴리프 | Ø11.0 | −5 .. −2 |

볼트는 혼의 관통홀을 지나 PLA 허브의 **황동 열간 인서트(M2)** 로 들어간다. 스피곳은 위치 결정용이며
토크는 볼트 8개가 받는다. 인서트 SKU와 삽입 공정은 §5.3/I04를 따른다.

**웹 경량화 구멍**: 리브 사이 6개 베이 중앙에 Ø30, 중심 반경 60mm, 웹을 관통한다. 각도는
`[-112.5,-67.5,-22.5,22.5,67.5,112.5]°`다. 구멍 가장자리와 리브 사이는 반경 60에서 약 7.4mm 남는다.
제거량은 8.48 cm³/바퀴다.

### 3.2 D0 타이어 형상과 질량

`rho_s <= r <= rho_t`, v=`[-b_sector/2,+b_sector/2]`의 방사 밴드를 별도 바디로 생성한다. D0는 공극을 만들지 않은 접촉 외형이며 실효밀도 0.494g/cm³를 **예비 질량에만** 사용한다. TPU 강성은 이 밀도로 추정하지 않는다.

D1은 실제 셀·외피·타이어 고정 방식과 출력 재료 벌크 밀도를 사용한다. 허니컴을 직접 만들면서 0.494를 다시 적용하는 이중 공극 차감은 금지한다. 셀 정의·벌크 밀도·끼움 공차가 없는 동안 D1 타이어는 BLOCKED(I03/I04)다.

### 3.3 반력 계산

`mg/N`은 평균 참고값이다. 설계 하중은 실제 접촉점과 CoM에 대해 다음 정적 평형을 풀어 얻는다.

```text
sum(F_i) + m*g_vector = 0
sum((p_i-p_COM) cross F_i) = 0
N_i = dot(F_i,n_i) >= 0
norm(F_tangent_i) <= mu_i*N_i
```

4족은 지지 상태가 세 가지로 나뉘며 각각 다른 성질을 갖는다.

| 지지 상태 | 접지 다리 | 반력 결정 | 정적 안정 |
|---|---|---|---|
| 4점 (굴림·정지) | 4 | **과구속.** 3자유도에 구속 4개 → 반력이 유일하지 않다 | 마진 크다 |
| 3점 (크롤 스윙) | 3 | 3×3 선형계로 유일 | **직사각형 배치에서 CoM이 정중앙이면 마진 0** |
| 2점 (트롯) | 2 대각 | 정적 평형 불성립 | 동적 제어 필수 |

- **4점**: 잉여 구속 1개다. 자동차와 같은 정정 초과 상태이며 타이어 컴플라이언스가 배분을 정한다.
  구조 입력으로는 정적 선형/원뿔 제약 안에서 각 `N_i`의 **최댓값**을 구해 보수적으로 쓴다.
  균등 분배(`mg/4`)를 자동 선택하지 않는다.
- **3점**: 유일해가 나온다. 음수 반력은 지지 상태 불성립으로 FAIL 처리한다.
- **2점**: 정적 해가 없다. 반력은 동역학 로그에서만 얻는다. **구조 입력으로 쓸 때는 `mg/2`를
  보수적 상한으로 표시**하고 실제 트롯 하중은 I07 측정으로 대체한다.

D0 회귀 예제: 접점 `(232.5,-160),(232.5,160),(-232.5,160),(-232.5,-160)`, CoM=(0,0).
4점 균등 가정에서 각 `8.87N`, 한 다리(앞우)를 든 3점에서 나머지 셋의 분담은
**`0 / 50 / 50 %`가 아니라 `50 / 0 / 50 %`도 아닌 경계 해**이며 CoM이 지지 삼각형의 빗변 위에
정확히 놓인다. 이 좌표는 회귀 예제이며 rev.4 실제 접점은 §11에서 재생성한다.

### 3.4 하중 케이스와 구조 판정

`N_ref`는 검증한 자세·CoM·지지 패턴 전체에서 해당 다리의 최대 정적 반력이다. 해당 값이 없으면
예비 스크리닝에만 `m_upper*g/3`을 사용하고 보수적 상한이라고 표시한다. 아래 배수는 3~5배 하중
요구를 구체화한 **준정적 검사 케이스**이며 실제 착지 충격을 측정했다는 뜻이 아니다.

| ID | 입력 | 경계조건 및 출력 |
|---|---|---|
| LC01 | 실제 정적 지지 반력과 모든 부품 자중 | 조립체 관절 반력·변위·응력 |
| LC02 | 접지점 수직 `5*N_ref` | 단일 다리 stage-1 장착면 고정, 전체 하중 경로 |
| LC03 | 접지점 ±축방향 `3*N_ref` | 부채꼴·포크·링크 각각과 조립체의 같은 방향 변위 |
| LC04 | 접지점 ±축방향 `5*N_ref` | 출력 방향별 강도·체결부·국부 응력 |
| LC05 | stage-2 실제 전류 제한에서의 최대 출력 토크 | 허브–리브–림 하중 경로, 혼·볼트군·스터브 |
| LC06 | 양쪽 로브 팁 각각에 `3*N_ref` | 수직 및 ±접선 방향을 별도 해석. **접촉면이 TPU 모서리**임을 명시하고 국부 접촉응력·마모를 함께 본다 |
| LC07 | 실제 정지 유지 하중 | 온도·시간을 포함한 크리프 시험 |
| **LC08** | **트롯 착지: 대각 2점에 각 `mg/2` + 수직 충격 3배** | **4족 고유. 6족에는 없던 케이스. 링크 굽힘·클레비스·허브** |

**LC02(반경 방향) 국부 검토** — 리브 간 스팬 88.4 mm, 고정-고정 근사 `M = F·s/8`:
`N_ref = 11.82 N`에서 `M` = 653 N·mm, 반경 방향 단면계수 `Z_rad` = 565 mm³ →
σ = **1.16 MPa, SF 41**. **반경 방향은 지배 하중이 아니다.** 지배는 LC03/LC04(면외)다.

LC05의 실제 제한값이 없으면 12V stall 3.0N·m를 **예비 구조 입력**으로만 쓴다. 정상 운전 허용치로
쓰지 않는다.

- PLA E=3200MPa, 강도 48MPa, G=1230MPa는 예비 해석 입력이다. 제작 판정에는 I04의 동일 출력
  조건·방향별 실험 자료를 사용한다.
- 강도 후보 목표는 SF≥4, LC03 부채꼴 변위≤0.53mm, 링크 비틀림≤0.10°다. 현재 후보가 통과했다는
  뜻이 아니다.
- 변위를 같은 힘·좌표·경계조건으로 비교한다. 백래시의 무부하 간극을 탄성 변형과 단순 합산해
  '강성 개선 불필요'로 결론 내리지 않는다.
- 메시를 세분해 변위와 특이점에서 떨어진 응력이 각각 5% 이내로 수렴하는지 기록한다.
- 인서트가 있어도 PLA 보스 인발·압궤·회전·크리프를 검사한다. SF<요구값과 실제 파단을 구분한다.

**4족 전환으로 하중이 줄어든 결과** (`N_ref` 14.94 → 11.82 N, −21%). 부채꼴 단면을 그대로 두면
안전율이 올라간다. **D0는 단면을 줄이지 않고 여유를 남긴다.** 경량화는 §15의 관문을 통과한
기준 부품을 만든 뒤 별도 후보로 진행한다.

**면외 단면 정의.** 축방향(±v) 힘에 대한 저항 단면은 림(두께 `t_rim`=3, 축방향 폭 `b`)과 양측
립(높이 `h_lip`=12, 두께 `t_lip`=3)으로 이루어진 ㄷ자다. 중립축은 축방향 중앙이고 최외단 거리는
`b/2`다. **모멘트 팔과 캔틸레버 길이는 서로 다르며 둘 다 명시한다.**

```text
I  = t_rim*b^3/12 + 2*( h_lip*t_lip^3/12 + h_lip*t_lip*((b-t_lip)/2)^2 )
Z  = I/(b/2)
Lm = R_tread - r_hub = 100.5      # 접지면에 힘이 걸릴 때 허브 뿌리의 모멘트 팔
Ld = r_lobe_tip - r_hub = 90.5    # PLA 판 자체의 캔틸레버 길이 (변형 계산용)
sigma = 5*N_ref*Lm/Z              # SF = 48/sigma
delta = 3*N_ref*Ld^3/(3*E*I)
```

| b | h_lip | 면외 I | 면외 Z | 변형 @3×N_ref | SF @5×N_ref | 판정 |
|---:|---:|---:|---:|---:|---:|---|
| **20** | **12** | **7256 mm⁴** | **725.6 mm³** | **0.377 mm** | **5.86** | **D0 채택 (여유 보존)** |
| 18 | 12 | 5562 | 618.0 | 0.492 | 4.99 | 경량화 후보 |
| 16 | 12 | 4120 | 515.0 | 0.665 | 4.16 | 변형 목표 초과 |
## 4. 회전축·포크·허브 조립

### 4.1 D0 포크와 모터 포락

내폭 `b_sector+2*clevis_gap=24mm`, 팔 두께 5mm, 포크 바깥 폭 34mm는 **판과 포크만의 D0 후보값**이다. 모터 몸체·혼·나사머리·베어링 고정부·배선의 전체 축방향 폭은 포함하지 않는다.

D0 포크 좌표는 stage-2 축 중심을 원점으로 하고 크랭크 두 번째 구간의 길이 방향을 e, v를 축방향, `f=e cross v`를 높이 방향으로 둔다. e는 §11의 `cos(q1+gamma)*u_i+sin(q1+gamma)*w`다. 포크의 **도달 길이는 22mm가 아니라 `R_tread + 2 = 124.5mm`** 다. 부채꼴은 stage-2 축을 중심으로 반경
122.5mm의 원판 전체를 쓸고 지나가므로, 그 원 안에 있으면서 축방향 `|v| <= 10`인 링크 재료는 회전 중
반드시 부딪힌다. 따라서 클레비스는 다음 한 줄로 정의한다.

```text
크랭크 링크에서 stage-2 축을 중심으로 반경 124.5mm, |v| <= b_sector/2 + clevis_gap = 12mm 인
원기둥을 빼낸다.  ->  남는 팔 두 개는 |v| 12..17mm, 즉 clevis_arm_t = 5mm 와 정확히 일치한다.
```

D0 구현 결과: 제거 체적 16.708 cm³, 링크 질량 86.433 g → **66.718 g**. 이 절삭 후 링크–부채꼴,
링크–타이어 교차가 0이 된다. 브리지는 e=`[-27,-22]`, v=`[-17,17]`, f=`[-22,22]mm` 박스로 정의한다.
링크 끝 27mm 구간과 브리지의 겹침은 미해결 접합 영역으로 표시한다.

**팔이 길어지면 비틀림 강성이 떨어진다.** 다만 팁에서 축·베어링이 두 팔을 다시 이어 주므로 닫힌
경로가 되며, 이것이 v1/v2의 외팔 지지를 클레비스로 바꾼 이유다. 실제 비틀림 강성은 축·베어링
사양이 정해진 D1에서 LC03/LC04로 확인한다. 정확한 모터 체결·베어링 지지는 I02 도면을 확보한 D1에서만 만든다. 포락을 실제 조립체로 집계하거나 이 겹침을 제작 무간섭으로 통과시키지 않는다.

XM430의 28.5mm를 회전축 방향 크기라고 가정하지 않는다. 도면/STEP의 기준면에서 몸체·혼·케이블 플러그를 포함한 실제 포락을 측정한다. D0 포락만 있는 모터는 질량용 블록과 실제 충돌 검증용 부품을 구분한다.

D0에서 제조사/기존 모터 CAD와 축 변환이 확보되면 그 형상을 사용한다. 없으면 해당 축에 좌표 마커만 놓고 `geometry_status=MISSING`으로 기록한다. 모터가 없는데 전체 간섭 PASS를 내지 않는다. MX-28AT 77g, XM430 두 종류 각 82g은 데이터시트 참고 질량으로 기록하되, CoM/관성이 없으면 null이다. 그때 구조 부품만의 질량 부분합과 누락 모터 개수를 따로 출력한다. 도면 없이 모터 크기·축 오프셋을 추측한 블록은 생성하지 않는다.

### 4.2 D1 허브를 생성하기 위한 필수 자료

I02에는 혼 부품번호/리비전, 도면 PDF 또는 STEP, 중심 체결과 주변 볼트의 지름·좌표·깊이, 혼 중심축/장착면, 베어링 정확한 품번, 스터브와 빠짐 방지 단면을 넣는다.

1. 혼 장착면을 축방향 기준 0으로 정한다.
2. 모터–혼–PLA 허브–스터브–베어링–포크의 단면을 실제 치수로 배치한다.
3. 혼 수용부는 필요한 깊이의 포켓으로 정의한다. **Ø19.5 관통홀은 기본값에서 삭제**한다.
4. 주변 체결 구멍은 제조사 좌표에서 가져온다. **2026-09-09 검수에서 기존 `SCONEv3 v8` Fusion 파일의
   실제 체결 형상을 측정해 아래를 확정했다.** 이 값은 추정이 아니라 형석 본인이 만든 조립체에서
   뽑은 것이다.

| 부위 | 측정값 | 근거 |
|---|---|---|
| XM430 혼 (HN12-N101) 원판 | Ø22.0 | `SCONEv3 v8` 모터 컴포넌트 최대 동축 실린더 |
| XM430 혼 주변 체결 | **Ø2.0 × 8개, PCD 16.0** | 같은 컴포넌트의 동축 그룹 |
| XM430 출력 샤프트 | Ø8.0 | 중앙 실린더 |
| MX-28AT 혼 주변 체결 | Ø1.6 × 16개, PCD 16.0 | MX-28 계열 컴포넌트 |
| 프레임 인서트 | Ø4.0, PCD 12.04 / 18.0 | 몸체-다리 프레임 |

   즉 **PCD 16은 맞고, 개수와 나사 규격이 틀렸다. 실제는 M2 8개다.** 기존 ‘M2.5×4, PCD16’ 표기는
   폐기한다. 중앙 M2.5 체결은 혼–모터 간 체결이며 혼–부채꼴 체결과 구분한다. [ROBOTIS 혼 자료](https://robotis.us/hn12-n101-set/)
5. 볼트 구멍 주변 잔여 재료, 나사 유효 길이, 나사머리 접근, 포켓 바닥, 샤프트 어깨·와셔·빠짐 방지, 하중 전달 경로를 단면도로 검사한다.
6. 반대쪽 Ø10 시트가 필요한 경우 앞쪽 포켓과의 잔여 벽을 별도 치수로 검증한다. 베어링 10×19×5mm는 품번 확인 전 포락 후보에 한정한다.
7. H7·동축도 0.05mm를 출력만으로 달성한다고 가정하지 않는다. 리머 가공/지그 등 실제 공정과 측정법을 I04에 연결한다.

도면에 필요한 치수가 없으면 해당 필드는 null로 유지하고 I02를 BLOCKED로 둔다. 구멍 없는 D0 모델과 접지 계산은 계속 진행할 수 있다.

### 4.3 축 정렬 검사

| 대상 | CAD 판정 |
|---|---|
| 판 중면 법선과 stage-2 축 | 단위벡터 내적 절댓값 ≥0.9999 |
| 혼축과 베어링축 | 두 축 직선의 최단거리≤0.05mm, 방향 내적 절댓값≥0.9999 |
| stage-2 축과 판 중심 | 판 중심에서 축 직선까지 거리≤0.05mm |
| 조향축과 부채꼴 중면 | 중립 자세에서 축 직선이 중면에 포함되는지 점-평면 거리와 방향으로 검사 |
| 실제 부품 동축도 | 제작도 공차와 실측 결과로 별도 판정 |

정렬이 맞아도 조향축에서 접지점까지의 트레일은 남는다. ‘스크럽 반경 0이므로 정지 조향 가능’이라고 판정하지 않는다.

## 5. 링크·요크·프레임 구조

### 5.1 크랭크의 정의

```text
link_a=90mm, link_b=110mm, gamma=25deg
L_link = hypot(link_a+link_b*cos(gamma), link_b*sin(gamma)) = 195.307179mm
phi_off = atan2(link_b*sin(gamma),link_a+link_b*cos(gamma)) = 13.770009deg
```

같은 두 축 사이 거리의 단일 강체 링크는 끝점 기구학이 같다. 꺾인 부재의 응력·질량·간섭·관성까지 직선 보와 같다는 뜻은 아니다.

D0 링크는 길이축을 따라 a 구간 뒤 +w 쪽으로 gamma만큼 꺾이는 b 구간이다. 각 구간에 폭 v=34mm, 높이 37mm, 벽 2.8mm의 직사각 폐단면을 sweep하고 꺾임은 두 구간의 미터 접합으로 닫는다. 내부 공극도 같은 중심선으로 이어지게 만든다. 정확히 두 끝만 개방하고 D0에는 경량화·배선 구멍을 뚫지 않는다. 꺾임에서 자기 교차 또는 끊긴 벽이 있으면 FAIL이다.

요크 D0는 다음 표의 직육면체 외곽과 균일 벽 두께를 갖는 중공 박스다. 장착 구멍과 배선 홀은 D1 도면에 따른다. 중공 박스 양 끝을 닫는 캡도 같은 벽 두께로 만든다.

| 부분 | 길이×폭×높이 mm | 벽 mm | 배치 |
|---|---|---:|---|
| 요크 #1 | 44×33×26 | 3.5 | 조향축부터 바깥 u 방향, z 중심 0. **아래 경고 참조** |
| 요크 #2 | 41×31×24 | 3.5 | stage-1 축을 끝 기준으로 바깥/안쪽 연결 포락. **아래 경고 참조** |

**경고 — 이 두 포락은 담아야 할 모터보다 작다.** 실제 모터 형상을 D0에 넣고 나서 측정한 결과다.

| 요크 | 포락 (내림차순) | 담을 모터 | 모터 (내림차순) | 부족량 |
|---|---|---|---|---|
| 요크 #1 | 44.0 / 33.0 / 26.0 | MX-28AT (혼 포함) | 50.6 / 45.1 / 35.6 | **6.6 / 12.1 / 9.6 mm** |
| 요크 #2 | 41.0 / 31.0 / 24.0 | XM430 (혼 포함) | 46.5 / 42.4 / 28.5 | **5.5 / 11.4 / 4.5 mm** |

D1에서 요크를 다시 정할 때 최소 요구치는 `모터 외형 + 2*(벽 3.5 + 여유 1) = 모터 + 9mm/축`이다.
즉 요크 #1은 최소 **59.6 × 54.1 × 44.6**, 요크 #2는 최소 **55.5 × 51.4 × 37.5** 가 필요하다.
축 순서는 실제 장착 방향에 맞춰 다시 배정한다. 이 값을 확정 치수로 쓰지 말고 I02 도면으로 검증한다.

요크 #2의 D0 길이축은 u, 끝면 중심은 stage-1 축, 반대 끝은 안쪽 u 방향이다. **네 다리 모두 같은 요크를 쓴다.** 6족의 중앙 다리용 66mm 연장형은 삭제했다. #1과 #2는 union하지 않고 부품별 포락으로 둔다. 모터 장착부와 연결 체결이 없는 동안 구조 검증은 D1 관문에서 BLOCKED다.

### 5.2 해석식의 사용 범위

구멍 없는 직선 박스에만 다음 예비식을 쓴다. 단위는 N, mm, MPa다.

```text
A = w*h-(w-2*t)*(h-2*t)
I_v = (w*h^3-(w-2*t)*(h-2*t)^3)/12
Z_v = I_v/(h/2)
J_thin = 4*((w-t)*(h-t))^2 / (2*((w-t)+(h-t))/t)
twist_rad = T*L/(G*J_thin)
```

w34/h37/t2.8/L195의 비교값: `J≈97492.6mm^4`, `Z≈3797.13mm^3`, PLA 밀도 1.18에서 질량 **84.27g**. 63.2g은 25% 재료 제거를 가정했던 rev.2 값이다. 구멍을 낸 뒤 같은 J를 유지하지 않는다.

rev.2 평균하중 14.94063N을 넣은 회귀 예제에서 `5*Wi*195/Z≈3.84MPa`, `SF≈12.5`다. `3*Wi*122.5` 비틀림 모멘트의 링크 끝 접지점 변위는 약 1.094mm다. 이는 예비식의 회귀 기준이며 D1 강도·변형의 합격 증거가 아니다.

### 5.3 제작 조건

- 구조재 PLA 선택은 유지한다. 정확한 필라멘트·프린터·노즐·선폭·레이어·방향·온도·건조 조건은 I04에서 고정한다.
- 3.5mm를 0.4mm의 정확한 9겹으로 표현하지 않는다. 슬라이서 실제 선폭과 벽 충전 상태를 확인한다.
- 형상을 공극까지 직접 모델링했으면 재료의 벌크 밀도를 사용한다. infill 효과를 밀도와 CAD 공극 양쪽에서 중복 반영하지 않는다.
- 구조용 인서트의 외경·길이·파일럿 홀·삽입 공정은 실제 SKU 자료로 정한다. 모든 인서트를 Ø3.4×4mm로 통일하지 않는다.
- 경량화는 검증된 무공 기준 부품을 만든 뒤 진행한다. 질량과 하중별 강성을 같은 CAD 리비전에서 비교한다.
- 파손 원인과 강성 개선율은 동일 조건의 조립체 시험 결과가 생긴 뒤 서술한다.

## 6. 자세·토크·도달거리

### 6.1 기준 자세

원점과 관절은 §11에서 정의한다. 하부 프레임 기준 하면은 z=-18mm이며 H는 그 면에서 지면까지의
수직 거리다. 원호가 바닥을 지지하고 stage-1 축 높이가 0인 경우:

```text
z_ground = frame_bottom_z-H
z_axle   = z_ground+R_tread
beta     = asin(z_axle/L_link)                고도각
q1       = beta-phi_off                       실제 모델 stage-1 좌표
arm      = L_link*cos(beta)                   stage-1 축 -> 접지점 수평거리
```

D0 H=255에서 `z_ground=-273`, `z_axle=-150.5`, `beta=-50.406090°`, `q1=-64.176099°`,
`arm=124.477485mm`다. 로브/팁 접촉 시 R 대신 실제 지지 높이 h(q)를 넣고 접촉 상태와 함께 푼다.

D0는 절대 프로파일 각 `alpha_abs=0`인 기준 자세를 사용한다. §11의 정의에 따라 `q2=alpha_abs-q1`이다.
이 자세는 CAD와 수학의 비교용이며 최적 정지 자세가 아니다. **`alpha_park` 최적값은 미정(null)** 이다.

### 6.2 자세 모드 — 스파이더에서 개까지

**stage-1 축이 이미 몸체 횡축과 평행하므로 `beta` 하나로 sprawl(스파이더) ↔ parasagittal(개)
전환이 된다. 새 자유도가 필요 없다.** 이는 v3에서 확인했으나 정식 기능으로 정의하지 않았던 항목이며,
rev.4에서 운용 모드로 승격한다.

| 모드 | beta | q1 | 차고 H | arm | 축거 | 3점 설계토크 | 4점 설계토크 |
|---|---:|---:|---:|---:|---:|---:|---:|
| 스파이더 (저속·험지) | −25.0° | −38.77° | 187 mm | 177.0 | 570 mm | 4.18 N·m (102%) | 3.14 N·m (77%) |
| 광폭 | −40.0° | −53.77° | 230 | 149.6 | 515 | 3.54 (86%) | 2.66 (65%) |
| **기준 (굴림 주행)** | **−50.41°** | **−64.18°** | **255** | **124.5** | **465** | **2.94 (72%)** | **2.21 (54%)** |
| 중간 | −60.0° | −73.77° | 274 | 97.7 | 411 | 2.31 (56%) | 1.73 (42%) |
| **개 (보행·계단)** | **−70.0°** | **−83.77°** | **288** | **66.8** | **350** | **1.58 (39%)** | **1.19 (29%)** |
| 개 최대 | −80.0° | −93.77° | 297 | 33.9 | 284 | 0.80 (20%) | 0.60 (15%) |

- 설계토크 = `2 * W_i * arm / 1000`. 계수 2.0 = **안전율 1.5 ÷ 외부 전달효율 0.75**다.
  0.75는 **혼 유격·베어링 마찰·케이블 저항 같은 관절 바깥의 손실**이며, 제조사 stall 값에 이미
  들어 있는 **내부 감속기 효율이 아니다**(§6.3). 같은 0.75를 두 번 적용하지 않는다.
  stall 4.1 N·m 대비 백분율.
- `W_i(3점)` = 11.82 N, `W_i(4점)` = 8.87 N, `W_i(트롯 2점)` = 17.73 N (m = 3.615 kg).
- 트롯 2점, 개 자세: 설계토크 **2.37 N·m (58%)**. **기준 자세에서 트롯을 하면 4.41 N·m(108%)로
  stall을 넘는다. 트롯은 `beta <= -60°`에서만 허용한다** (−60°에서 3.46 N·m, 84%).
- **스파이더 자세는 3점 지지에서 stall을 넘는다(102%).** 4점 지지 굴림 전용으로 제한하고,
  다리를 드는 동작은 `beta <= -40°`에서만 수행한다. 이 제한을 B10 검색과 제어기에 강제한다.
- 이 표는 준정적 계산이며 실제 운전 판정은 I07의 토크–속도/전류/열 자료가 필요하다.

**보행 속도는 개 자세가 더 빠르다.** 보폭은 `beta` 스윕이 만들고 `dx/dbeta = L*sin|beta|`이므로
다리가 설수록 같은 관절각에 발이 더 많이 움직인다.

| beta 중심 | dx/dbeta | ±15° 보폭 | 트롯 사이클 0.65 s 기준 속도 |
|---:|---:|---:|---:|
| −50° | 150 mm/rad | 78 mm | 0.120 m/s |
| −70° | 184 | 95 | **0.146 m/s** |
| −80° | 192 | 100 | 0.154 m/s |

사이클 시간 0.65 s는 W350 무부하 276°/s의 1/3(92°/s)을 가정한 값이다. **실측이 아니다.**

### 6.3 접지 토크 계산

원형 접지호를 돌리면 접촉하는 재료 점이 바뀐다. `x_contact=R*sin(alpha)`를 일반 접지식으로 사용하지
않는다. 최종 형상에서 §2의 지지점을 구한 뒤 관절별 요구 토크를 계산한다.

```text
a_j = 세계 좌표계의 관절 단위축
p_j = 관절축 위의 점
F_k = 해당 관절 아래 부품에 가해지는 외력, 중력 포함
tau_hold_j = -sum_k dot(a_j, (p_k-p_j) cross F_k)
```

stage-1에는 타이어 접촉력뿐 아니라 distal 링크·모터·포크 등의 자중이 포함된다. stage-2에는 회전하는
부채꼴·타이어·허브의 자중을 포함한다. 동일 부품 자중을 같은 식에 두 번 넣지 않는다.

제조사 토크는 감속기 출력축 기준이다. **내부 감속기 효율을 다시 나누지 않는다.** §6.2의 계수
2.0에 들어 있는 0.75는 관절 바깥의 전달 손실(`external_loss_factor`)이며 내부 감속기 효율과 다른
값이다. 이름이 겹쳐 혼동하지 않도록 `params.json`의 키를 `drive_efficiency`에서
`external_loss_factor`로 바꿨다. 추가 설계 여유를
쓰면 `design_factor`로 명명하고 요구 토크에 한 번 적용한다. D0 스크리닝 계수는 1.5다.

ROBOTIS stall 토크는 순간 최대치다. 전압·속도에 따른 운전점, 전류, 유지 시간, 열 시험 없이
'stall의 39%이므로 연속 유지 가능'이라고 판정하지 않는다.
[W350 자료](https://emanual.robotis.com/docs/en/dxl/x/xm430-w350/),
[W210 자료](https://emanual.robotis.com/docs/en/dxl/x/xm430-w210/)

### 6.4 정지·보행 자세 검색의 고정 절차

B10에서 수행한다. 기구학 계산은 진행할 수 있지만 I07의 전류/열 한계가 없으면 최종 자세의 운전
판정은 BLOCKED다.

1. D0의 기본 질량은 현재 CAD/BOM 추정 합계로 갱신한다. 3.615kg를 고정하지 않는다.
2. `beta` 후보 `[-25,-40,-50.406,-60,-70,-80]`, 절대 스핀각 `0..355°`를 5° 간격으로 평가한다.
   첫 검색에서는 모든 다리 동일 beta·동일 alpha, yaw=0으로 제한한다.
3. 각 alpha에서 h와 접촉 후보를 구하고 H를 만족하는 q1을 해석적으로 구한다. asin 정의역 밖,
   사용 범위 밖, 음수 반력, 안정마진 또는 간섭 위반 후보는 제외한다.
4. 지지 패턴을 **4점 / 3점(다리별 4가지) / 트롯 대각 2점(2가지)** 전부 검사한다. 3점과 2점은
   CoM 이동 요구량을 함께 출력한다.
5. 하드웨어 운전 한계가 있으면 `max(abs(tau_required_j)/tau_allowed_j)`를 최소화한다. 같은 값은
   질량, H 오름차순, alpha 오름차순으로 선택한다. 허용 토크가 없으면 요구 토크 벡터와 기구학
   결과만 출력하고 winner를 null로 둔다.
6. 선택 후보 주변 beta ±5°를 0.5°, alpha ±5°를 0.5°로 재계산한다. 후보가 없으면 b/L/트랙을
   임의 변경하지 않고 G04=FAIL과 위반 조건을 출력한다.

### 6.5 조향·선회와 계단

**직진 굴림에는 조향이 필요 없다.** 진행 방향은 다리가 뻗는 방향(±x)이고 네 부채꼴이 모두 같은
방향으로 구른다. yaw는 ① 보행 시 횡방향 발 배치 ② 선회 ③ 게걸음에 쓴다.

**선회는 좌우 바퀴 속도차를 우선한다.** 조향 선회는 실제 접촉력·미끄럼·토크를 검증한 경로만
허용 목록에 추가한다. 부채꼴 폭이 20 mm뿐이라 스키드 시 횡방향 끌림 저항이 작다는 것은 설계
근거이며 측정값이 아니다. I09에 마찰과 선회 반경 요구를 넣는다.

조향은 우선 스윙에서 수행한다. `N<=0.15Wi`는 자동 운전의 확정 센서 임계값이 아니다.
지지 중 조향 토크는 트레일 182.5 mm, μ=1, N=11.82 N에서 **2.16 N·m**이며 MX-28AT stall
2.5 N·m에 근접한다. 스윙 중(N ≤ 0.15W)에는 0.32 N·m다.

계단 검사는 다음 순서를 고정한다: 평지 정지 → 자세를 개 모드로 전환 → **남은 세 다리 조향각 재배치로
지지 삼각형 확대** → 단일 다리 들기 → 계단 상면에 접촉 → 지지 전환 → 몸체 이동 → 후속 다리 이동 → 하강.

**CoM은 굴림으로 옮길 수 없다.** 미끄럼 없이 구르면 접지점도 몸체와 같은 거리만큼 함께 이동하므로
지지 다각형 대비 CoM 위치는 변하지 않는다. 또 네 발을 딛은 채로 몸체를 수평 이동시키는 것도
불가능하다(다리 길이가 모두 같아야 몸이 수평이므로). 따라서 마진은 **지지 다리의 조향각 재배치**로
만든다(§7.3, 최대 111.0 mm). 몸체를 기울여 만드는 방법도 있으나 80 mm에 롤 15.7°가 필요해 비효율적이다.

관절 끝점 높이 차이 346mm만으로 200mm 계단 통과를 판정하지 않는다. 절차의 성립은 G04에서 검증한다.
## 7. 배치·조향 간섭·안정성

### 7.1 몸체 좌표에서의 중심 이동

조향축은 `(side_x*50, side_y*160, 20.5)`mm다. stage-1 축 높이는 0이며 yaw=0에서 `x=side_x*108`이다.
6족의 중앙 다리 요크 연장 25mm(`mid_yoke_extension_mm`)는 중앙 다리가 없어졌으므로 **삭제**한다.

```text
u_i  = Rz(yaw_i)*(side_x_i,0,0)
v_i  = Rz(yaw_i)*(0,side_x_i,0)
p1_i = (side_x_i*50, side_y_i*160, 0) + 58*u_i
p2_i = p1_i + L_link*(cos(beta_i)*u_i + sin(beta_i)*z_unit)
발_i = p2_i - (0,0,R_tread)        # 원호 접촉일 때만
```

yaw를 주면 발이 조향축 둘레로 반경 `58+arm`의 원을 그린다. 기준 자세에서 이 반경은 **182.478 mm**다.
`e(psi)=R*abs(sin psi)+(b/2)*cos psi` 같은 고정 중심 근사식으로 다리 사이 간섭을 판정하지 않는다.

rev.3의 `psi_max` 파라미터는 삭제 상태를 유지한다. 대신 아래 두 가지를 쓴다.

- **같은 쪽(좌현끼리 또는 우현끼리) 앞뒤 다리 대칭 벌림 한계 = ±64°.** 이 이상 벌리면 앞뒤 부채꼴
  중심거리가 `2*R_tread + 10 = 255 mm` 아래로 떨어진다. `params.json`의 `yaw_search_deg`는
  여유를 두고 **±60°** 로 둔다.
- 그 밖의 조합은 **검증한 경로 목록**으로만 허용한다.

### 7.2 간섭 검사의 실행 범위

B09는 다음을 모두 수행한다. 접촉할 의도가 있는 부품 쌍은 이름·자세·허용 접촉 방식까지 명시한
`allowed_contacts.json`에만 제외한다. 처음에는 지면–타이어와 고정 조립 접합면만 허용한다.

1. 기준 자세: 4개 다리, 몸체, 탑재물, 모터 포락, 포크 전체.
2. 단일 다리 검사: 다른 다리는 기준 자세에 고정하고 yaw `[-60,60]°` 5° 간격, q1 `[-110,115]°`
   5° 간격, q2 `0..355°` 5° 간격. 이 범위는 D0 탐색 범위이며 실제 하드스톱이 아니다.
3. 모든 다리 쌍(6쌍)의 기준 높이 검사: 두 yaw를 각각 `[-60,60]°` 5° 격자로 독립 변화. 같은 쪽
   앞뒤 쌍의 ±60° 반례를 반드시 포함한다.
4. **앞뒤 여유 검사**: `beta`를 `[-80,-25]°`로 훑으며 앞뒤 부채꼴 포락(반경 `R_tread`의 원기둥)
   사이 거리를 확인한다. D0에서 최솟값은 `beta=-80°`의 **38.83 mm**다. `beta=-85°`면 5.0 mm로
   떨어지므로 `beta` 하한을 **−80°** 로 고정한다.
5. q2는 회전 전체를 감싸는 보수적 포락으로 먼저 검사한다. 포락이 겹친 쌍만 실제 부채꼴 형상과 q2
   조합으로 상세 검사한다. 포락 교차를 실제 메시 충돌로 보고하지 않는다.
6. 실제 보행·조향 궤적은 시작부터 끝까지 **12개 관절**을 함께 검사한다. 각도 최대 증분 1°로
   시작하고, 부품 표면의 최대 이동이 최소 여유의 절반보다 작도록 분할한다. 거리 하한을 보장할 수
   없으면 연속 충돌 검사 또는 추가 분할로 확인한다. 해결되지 않은 구간은 PASS가 아니다.
7. 출력: 부품 쌍, 최소거리, 관절각 12개, 경로 시각, 교차 형상, 화면 캡처. 다리의 비접촉 이동 부품
   간 후보 최소 여유는 10mm다. 포크 내부의 의도된 2mm 여유는 별도 쌍 규칙을 적용한다.

**좌우 여유는 문제가 되지 않는다.** yaw=0에서 좌우 부채꼴 안쪽면 사이는 `T - b = 300 mm`다.

단일 다리 격자 검사는 전체 12차원 공간의 무간섭 증명이 아니다. 격자에 충돌이 있으면 그 자세를
기록하고, 실제 경로가 사용하지 않음을 검증한 경우에만 해당 경로를 허용할 수 있다.

### 7.3 무게중심과 지지 패턴

접점은 §7.1의 변환과 §2의 실제 프로파일에서 계산한다. CoM은 부품별 질량과 자세로 계산하고,
페이로드·배터리 위치 오차 범위도 포함한다.

평지 정적 안정마진은 접점의 볼록 다각형 경계까지 CoM 수평 투영의 **부호 있는 최소거리**다.
내부는 양수, 외부는 음수다.

**4점 지지 (굴림·정지).** 접점 `(±232.478, ±160)`.

| 항목 | 이전 후보값 (CoM z=+12 가정) | **D0 실측 (2026-09-09 검수)** |
|---|---:|---:|
| CoM (몸체 좌표) | (0, 0, +12) | **(0.674, 8.923, −65.076)** |
| 지면 위 CoM 높이 | 285 mm | **207.92 mm** |
| 4점 정적 마진 | 160.0 mm | **151.08 mm** |
| 전도각 롤 | 29.31° | **36.00°** (나쁜 쪽) / 39.09° (반대쪽) |
| 전도각 피치 | 39.20° | **48.11°** (나쁜 쪽) / 48.27° |

**실측 CoM이 가정보다 77 mm 낮아 전도 여유가 오히려 커졌다.** 다리가 아래로 뻗어 질량을 끌어내리기
때문이다. 이 값은 현재 CAD 소계(3.115 kg) 기준이며 SPDB·포크·혼·베어링·체결·배선이 빠져 있다.
빠진 것 중 포크·혼·베어링은 다리(낮은 곳)에, SPDB는 데크(높은 곳)에 있으므로 최종값은 이 사이에
놓인다. B05가 전체 BOM을 채우면 이 표를 다시 생성한다.

**전도각 두 가지를 구분한다.** §16.2의 기준 계산은 CoM 수평 위치를 원점으로 두므로
롤 **37.58°** / 피치 **48.19°** 를 출력한다. 위 표의 36.00° / 48.11° 는 실측 수평 오프셋
`(0.674, 8.923)` 까지 반영해 **불리한 쪽**을 적은 값이다. 두 값이 다른 것은 오류가 아니라
가정이 다른 것이며, 판정에는 불리한 쪽을 쓴다.

**3점 지지 (크롤).** 네 발이 직사각형이면 한 다리를 들었을 때 남은 삼각형의 빗변이 CoM을 정확히
지나므로 마진은 **0.000 mm**다. 네 다리 어느 것을 들어도 같다. 이것은 4족 직사각형 배치의 기하
성질이며 설계 결함이 아니다. 해결책은 다음과 같다.

| 방법 | 얻는 마진 | 비용 | 판정 |
|---|---:|---|---|
| 아무것도 안 함 | 0.0 mm | — | 불가 |
| 몸체 롤/피치로 CoM 이동 | 80 mm에 **롤 15.68°** | 자세 크게 흐트러짐 | 비효율 |
| **지지 다리 3개 yaw 재배치** | **104.4 mm** (실측 CoM) / 111.0 mm (CoM 원점) | 스텝마다 조향 동작 추가 | **채택** |
| 트롯(동적 2점) | 정적 마진 개념 없음 | 균형 제어 필요 | 속도용 별도 모드 |
| 굴림으로 CoM 이동 | **0 mm (효과 없음)** | — | 사용 금지 |

**굴림은 CoM을 옮기지 못한다.** 미끄럼 없이 구르면 접지점이 몸체와 같은 거리만큼 함께 이동하므로
지지 다각형 대비 CoM 위치가 변하지 않는다. 이 사실을 보행 계획에 반드시 반영한다.

yaw 재배치 해는 `yaw_search_deg = ±60`, 다리 쌍 최소거리 255 mm 제약에서 5° 격자로 구했다.

| 드는 다리 | 지지 다리와 yaw | 마진 |
|---|---|---:|
| FL | FR +45° / RR +15° / RL −60° | 104.44 mm |
| FR | FL −45° / RR +60° / RL −60° | 116.50 mm |
| RL | FL +60° / FR −60° / RR −45° | 105.43 mm |
| RR | FL +40° / FR −60° / RL +45° | 117.50 mm |

위 표는 **D0 실측 CoM (0.674, 8.923)** 로 다시 푼 결과다. CoM을 원점으로 두면 네 경우 모두
110.97 mm로 같지만 실제 CoM은 약간 치우쳐 있어 다리마다 값이 달라진다. 최악은 FL을 들 때
**104.44 mm**이며 목표 80 mm를 넘는다. yaw 고정이면 −7.73 ~ +7.73 mm로 사실상 0이다.

yaw ±45°로 제한해도 96.2 mm, ±30°로 제한해도 72.3 mm가 나온다. 목표 80 mm는 **±45° 이내에서
달성**된다. 이 값들은 CoM=(0,0), 기준 자세, 평지 기준이다. 실제 CoM 범위와 자세에서 다시 계산하고,
실패하면 배치를 조정한 새 후보로 다시 검사한다. 경사·계단·가속 중 동적 전도는 평지 정적 마진과
별도 결과로 저장한다.

### 7.4 굴림 중 부채꼴 위상 배치

네 부채꼴의 스핀 위상을 어떻게 어긋나게 두는지가 굴림 승차감을 정한다. 강체는 항상 3점 이상으로
지면에 놓이므로 **위상이 정하는 것은 접지 개수가 아니라 몸의 흔들림 크기**다.

계산 방법: 각 발 위치에서 지지함수 `h(q+offset_i)`를 구하고, `plane(x,y) >= h_i`를 만족하면서
원점 높이가 최소가 되는 평면을 푼다(4개 중 3개 조합을 모두 풀어 실현 가능한 최저해 선택).

| 위상 배치 (FL/FR/RL/RR) | 상하동요 | 피치 | 롤 | 접지 수 |
|---|---:|---:|---:|---:|
| 0 / 0 / 0 / 0 (전부 동상) | 33.25 mm | 0° | 0° | 4 |
| 0 / 0 / 180 / 180 (앞짝·뒤짝) | 16.62 mm | 4.09° | 0° | 4 |
| 0 / 180 / 0 / 180 (좌짝·우짝) | 16.62 mm | 0° | 5.93° | 4 |
| **0 / 180 / 180 / 0 (대각짝)** | **0.00 mm** | 4.09° | 5.93° | **3~4** |
| 0 / 90 / 180 / 270 | 3.82 mm | 4.09° | 5.93° | 3~4 |

**대각짝이 0이 되는 조건은 `접지호 >= 180°` 하나뿐이다.** 접지호가 180°보다 좁으면 비접지 구간이
180°보다 넓어져 대각 두 발이 동시에 그 구간에 들어갈 수 있다. 접지호 195°는 이 조건을 만족한다.
개구각을 더 키우려면 로브 각을 줄여 접지호 180°를 지켜야 한다.

**D0 기본은 대각짝 180°다.** 이유: 개구부(45°)가 180° 떨어진 두 발에서 동시에 바닥을 향할 수 없어
대각 두 발 중 하나는 항상 `h = R_tread`다. 직사각형 배치에서는 원점 높이가 대각 두 발 높이의
평균이므로 결과가 정확히 `R_tread`로 일정하다. 즉 **몸이 위아래로 전혀 움직이지 않는다.**
라이다 스캔 평면과 스테레오 광축이 상하로 흔들리지 않는 것이 가장 큰 이점이다.

기울기가 부담되면 앞짝·뒤짝(피치만 2.29°) 또는 좌짝·우짝(롤만 3.32°)으로 바꾼다. 둘 다 4점 접지를
유지하는 대신 상하동요 9.28 mm를 받는다. 어느 배치를 쓰든 **위상 오차가 누적되면 성질이 무너지므로**
스핀 위상 동기 오차 허용치를 I07에서 정하고 제어기에서 유지한다.

이 표는 강체·평지·미끄럼 없음 가정의 기하 계산이다. 서스펜션 없음, 타이어 변형 무시, 동적 효과
무시다. 실제 승차 특성은 I07/I09의 주행 시험으로 확인한다.
## 8. 탑재 부품·전원·질량

### 8.1 부품 후보와 확인 자료

| 부품 | 유지하는 선택 | D0 포락/질량 참고 | D1에 필요한 입력 |
|---|---|---|---|
| LiDAR | YDLIDAR T-mini Plus | 38.6×38.6×33.9mm, 45g | I05 도면·리비전·핀 번호·스캔 평면 |
| 스테레오 | Waveshare IMX219-83 | 85.2×24×20.3mm, 30g 추정 | I05 STEP/홀·광축·FPC·캘리브레이션 |
| 인터페이스 | ROBOTIS U2D2 | 48×18×14.9mm, 9g | 보유품 USB-C/Micro-B 확인 |
| 컴퓨트 | Jetson Nano Dev Kit B01 | 100×80×29mm, 145g 추정 | I05 보드·방열판·홀·플러그·팬 실측 |
| 배터리 | 4S 2200mAh 후보 | 91.6×43.1×23.6mm, 204g 참고 | I06 정확한 SKU·셀 조건·배선 포함 외형 |
| 전원 | 12V/5V 강압과 SPDB | 모듈 외형 미정 | I06 정격·과도 응답·보호 회로 |

포락 치수는 제조사 표의 축 순서를 그대로 세계 좌표로 해석하지 않는다. §9의 D0 XYZ 정의를 사용하고 실제 STEP과의 변환은 I05에 저장한다.

U2D2는 모터 전원을 공급하지 않는다. 현행 USB-C 제품과 2025년 8월 이전 Micro-B 제품을 구분한다. [ROBOTIS U2D2 자료](https://emanual.robotis.com/docs/en/parts/interface/u2d2/)

### 8.2 전원 구조와 반드시 채울 정격표

4S 공칭 14.8V/만충 16.8V는 모터의 입력 상한 14.8V를 넘는다. **12V 강압을 사용한다.** 배터리 실제 방전 하한은 셀 제조사 조건과 컨버터 dropout으로 결정하며 13.2V를 확정 컷오프로 쓰지 않는다. [MX-28 사양](https://emanual.robotis.com/docs/en/dxl/mx/mx-28/)

```text
4S 배터리 → 입력 퓨즈/역극성 보호/주 스위치
          ├→ 모터 전원 차단 경로 → 12V 강압 → 보호된 모터 분기
          └→ 5V 강압 → Jetson, LiDAR 별도 전원 경로
Jetson USB → U2D2 → TTL 통신선
센서/통신 기준 접지는 회로의 지정된 공통 접지에 연결
```

이 그림은 회로 토폴로지다. e-stop의 실제 접점·전류 정격·우회 전원 유무와 차단 후 기체 지지 상태는 I06에서 검증해야 한다.

12V stall 전류의 참고 합은 한 다리 1.4+2.3+2.3=6A, **12개 합 24A**다. 정상 전류나 필수 컨버터 정격을 뜻하지 않는다. 기존 ‘12V 10A/5V 5A/30A 입력 퓨즈/5A 분기 폴리퓨즈’는 확정 부품 선정에서 내려 **비교 후보**로 둔다.

I06 정격표는 각 전원 경로마다 다음 열을 포함한다:

`source, load_ids, normal_A, rms_A, peak_A, peak_duration_ms, current_limit_A, voltage_min_max, wire_AWG_length, connector_SKU_rating, fuse_SKU_curve, converter_SKU_derating, evidence`.

1. 전류 제한·기동 순서·모터 duty를 I07의 동작과 연결해 레일 부하를 계산한다.
2. 커넥터·전선·동박·비아·퓨즈의 시간별 허용 전류를 함께 검사한다. JST EH는 AWG22에서 3A 정격이므로 5A 폴리퓨즈가 자동으로 보호한다고 가정하지 않는다. 10A용 ‘2.54mm 4P’ 소켓은 삭제하고 정확한 SKU와 핀별 정격을 정한다. [JST EH](https://www.jst-mfg.com/product/index.php?series=58)
3. 전류 제한에 의존하면 실제 제한 동작과 과도 펄스를 시험한다. 다이나믹셀 연결 규격 때문에 한 경로의 허용 전류를 넘는 경우 모터별 전원 분기 또는 동작 제한을 설계하고 회로로 입증한다. 통신과 전원 분기를 혼동하지 않는다.
4. 정지→동시 기동, 방향 반전, 감속/하강, 잠금, 저전압에서 레일 전압을 측정한다. 2000µF는 추가 5A를 1V 강하까지 약 0.4ms만 담당한다.
5. 모터가 되돌리는 에너지를 컨버터가 수용하는지 확인한다. 역전류 불가 벅이면 별도 에너지 흡수/클램프 경로가 필요하다. 부품 미선정 상태에서 TVS 하나로 해결됐다고 표시하지 않는다. [TI 역전력 설명](https://www.ti.com/document-viewer/lit/html/SSZT878/GUID-72E4FF4E-0508-4018-A599-5B6605492BD5)
6. Jetson 입력에 USB/CSI 부하가 포함되는지 구분한다. 문서상 4A와 LiDAR 기동 1A만 합쳐도 5V 5A에는 여유가 없다.
7. INA226은 측정기다. 셀별 저전압 판단·실제 차단·재기동 조건을 별도 구현한다. I06이 없으면 PCB 발주/전원 투입 준비 판정은 BLOCKED다.

### 8.3 센서 운용과 시야

IMX219-83은 하드웨어 프레임 동기화를 지원하지 않으며 IMU와 영상도 동기화되지 않는다. 카메라 두 개의 CSI와 IMU용 I²C를 모두 배선하고 타임스탬프·노출·움직임의 영향을 측정한다. [Waveshare 공식 문서](https://www.waveshare.com/wiki/IMX219-83_Stereo_Camera)

깊이 오차식 `sigma_z=z^2*sigma_d/(fx*baseline)`에는 해상도, 실제 보정 fx, baseline, 시차 오차 sigma_d를 함께 기록한다. 기존 1m에서 3.6mm는 fx≈2317px, baseline≈60.1mm, sigma_d≈0.5px라는 정적 가정이며 이동 중 정확도를 보장하지 않는다.

D0는 **광학 중심**을 (70,0,70)mm, 광축을 전방(+x)에서 30° 하향으로 정의한다. H255 지면 -273mm에서 높이는 343mm, 수직 FOV50° 가정의 지면 교점은 광학 중심 바로 아래에서 **240.2–3920.6mm 전방**이다. 이 좌표는 보드 중심이 아니다. D1에서 광축–홀 변환으로 브래킷을 만든다. 좌표와 방향 규칙은 §9.2에 있다.

LiDAR D0 베이스는 (0,-20,70)mm, 스캔 평면 높이는 베이스+26.3=96.3mm로 둔다. 실제 도면과 일치하면 이 값을 유지한다. 본체·배선·마스트 차폐를 광선 검사하고, **4족은 앞다리가 근거리 전방을 크게 가리므로** 다리의 일시 차폐는 각도·지속시간·최대 연속 가림을 보고한다. 단순 각도 마스킹이 시야를 복원한다고 주장하지 않는다.

T-mini Plus의 5V/typical 340mA/기동 최대 1A는 제조사 자료 참고값이다. [데이터시트 URL](https://www.ydlidar.com/Public/upload/files/2024-05-24/YDLIDAR%20T-mini%20Plus%20Data%20Sheet_V1.1%20%28240131%29.pdf)은 이전 검토에서 검색에 남은 원문 내용은 확인했으나 직접 다운로드가 404였다. 다음 에이전트는 현행 제조사 자료 또는 보유품 도면을 I05에 저장하고 핀 번호·도면을 확정해야 한다.

### 8.4 질량 예산의 처리

**총질량 3.615 kg은 확정값이 아니라 하중 입력용 후보값(CANDIDATE)이다.** 산출 경로는 다음 한 줄이다.

```text
3.615 kg = 4.945 kg (rev.3 D0 무공 형상 6족 추정) - 2 x 0.665 kg (다리 모듈)
다리 모듈 0.665 kg = 모터 0.241 kg (77+82+82 g) + 다리 구조 0.424 kg
```

이 값은 **몸체 축소분을 반영하지 않았다.** 몸체 y 길이가 425→350 mm로 줄었으므로 실제 값은 더
가벼울 가능성이 높다. 즉 보수적 상한 쪽이다. rev.2 BOM의 23개 행 합계 4569.2g은 산술적으로
맞으며 올바른 분류는 모터 1446g, 구조 2285.2g, 전장·센서·배터리 568g, 배선·체결류 270g이다.
기존 '구조 2777 / 전장 346'과 증가분 전부가 전장이라는 설명은 폐기 상태를 유지한다.

D0는 무공 링크·무포켓 웹·미가공 허브를 사용하므로 rev.2 질량과 달라진다. **139.8g 판, 63.2g 링크,
4.569kg 총질량에 CAD 밀도를 맞추지 않는다.** 질량 예산은 생성 결과에서 다시 계산한다.

모터 구성만 확정이다.

| 모터 | 역할 | 개수 | 단품 g | 합 g |
|---|---|---:|---:|---:|
| MX-28AT | 조향 (yaw) | 4 | 77 | 308 |
| XM430-W350-T | stage-1 (q1) | 4 | 82 | 328 |
| XM430-W210-T | 부채꼴 스핀 (q2) | 4 | 82 | 328 |
| | | **12** | | **964** |

`parts_manifest.json`의 부품마다 `part_id, instance_id, revision, role, mass_source, mass_kg,
com_local_m, inertia_com_local_kgm2, geometry_hash, source_file`을 기록한다. mass_source는
`CAD_BULK`, `ENVELOPE_EFFECTIVE`, `DATASHEET`, `MEASURED` 중 하나다. 값이 없는 항목은 null이고
누락 개수와 부분합을 함께 보고한다.

- PLA: 실제 생성한 재료 체적×예비 벌크 밀도. D1에서는 출력 질량과 대조한다.
- D0 TPU: 외형 체적×실효밀도; 물리적 강성 모델은 미확정이라고 표시한다.
- 모터/탑재물: 도면 또는 측정 질량을 1회만 집계한다. 혼·베어링·포크 포함 범위를 명시해 중복을 막는다.
- 케이블·플러그·인서트·팬·배터리 배선을 포함한다. 중앙 요크 연장분은 삭제되었으므로 계상하지 않는다.
- 전체 질량 상한 후보는 **3.90 kg**이다. 초과하면 FAIL로 보고하고 밀도·경량화율을 임의 변경하지
  않는다. 경량화 효과는 변경 전후 동일 하중으로 재검증한다.
- B05가 총질량을 갱신하면 §3의 `N_ref`, §6의 설계토크, §7의 전도각을 **모두 다시 계산**한다.
  3.615 kg에 맞추어 다른 표를 고정하지 않는다.

## 9. 몸체·배치·배선·PCB

### 9.1 D0 몸체 형상

좌표는 mm다. 하부 기준 하면 z=-18은 모든 높이 계산의 원천이다. 몸체는 **앞뒤 130 mm(x±65),
좌우 350 mm(y±175)** 다. 좌우가 긴 이유는 조향축이 `y=±160`에 있어야 트랙 320 mm가 나오기
때문이다. 앞뒤 방향 크기는 다리가 만들므로(축거 465 mm) 몸체 자체는 짧아도 된다.

1. 외곽은 x±65, y±175의 사각 둘레다. 바깥 박스빔은 평면 폭 12, 높이 10, 벽 2.4mm이며
   z=-18..-8에 둔다. 코너는 미터 접합으로 닫는다.
2. **횡 리브**는 y=-160 / 0 / +160, 두께 2.4, x=-53..53, z=-18..-8이다. y=±160 리브가 조향
   모터 장착면이다.
3. **종 리브**는 x=-50 / +50, 두께 2.4, y=-163..163, z=-18..-8이다. 앞 조향축과 뒤 조향축을
   직선으로 잇는 **주 하중 경로**이며 6족에는 없던 부재다. 4족은 앞뒤 다리 사이 거리가 멀어
   이 경로가 없으면 굽힘이 몸체 판으로 몰린다.
4. 중앙 판은 x=-53..53, y=-163..163, z=-15..-13이다. D0는 포켓 없이 union한다.
5. 데크는 x±65, y±175, z=28..30의 별도 판이다. 기둥·체결은 아직 도면이 없는 포락 후보이며
   D1에서 추가한다.
6. 배터리 슬롯·도어·마스트·센서 브래킷은 아래 포락과 작업 경로를 먼저 배치한다. 정확한 도면
   없이 출력 가능한 레일/마스트라고 표시하지 않는다.

조향 모터는 y=±160 횡 리브에 붙으므로 **리브–모터 접촉은 의도된 접촉**이다. `allowed_contacts.json`에
쌍 이름과 접합면을 명시하고, 그 외의 교차는 모두 FAIL로 본다. rev.3의 '하부 전체 z=-18..-15'와
높이 10mm 빔의 모순은 해소된 상태를 유지한다. '강성 5배/165g'은 확정값에서 삭제 상태를 유지한다.

### 9.2 D0 탑재물의 좌표와 방향

아래 XYZ는 스테레오를 제외하고 **몸체 좌표 축 방향의 포락 크기**다. 스테레오의 크기는
폭/보드 높이/광축 방향 두께이며 바로 아래 변환을 적용한다. 원래 부품의 L/W 명칭을 다시 해석하지
않는다. `center`는 XYZ 중심, `base`는 XY 중심과 최저 z, `optical`은 광학 중심이다.

**좌표계가 rev.3에서 바뀌었다. +x가 전방이므로 카메라는 +x를 본다.** rev.3의 `(0,205,40)`을
그대로 옮기지 않는다.

| ID | 기준 | 위치 XYZ mm | 포락 XYZ mm | 규칙 |
|---|---|---|---|---|
| battery_slot | center | (0,95,3) | (50,100,32) | 빈 공간 포락, 질량 제외 |
| battery | center | (0,95,3) | (43.1,91.6,23.6) | 긴 변은 y |
| U2D2 | center | (0,-60,3) | (48,18,14.9) | 포트 방향 D1에서 확인 |
| SPDB | base | (0,-100,32) | (70,90,22) | 부품 포함 포락, 모듈 중복 주의 |
| Jetson | base | (0,68,32) | (100,80,29) | I/O 면 −y 후보 |
| mast_envelope | base | (0,-20,30) | (60,60,40) | 지지대 보수적 포락, 질량 제외 |
| lidar | base | (0,-20,70) | (38.6,38.6,33.9) | 스캔 평면 z=96.3 후보 |
| stereo | optical | (70,0,70) | (85.2,24,20.3) | 아래 광축·보드 방향 규칙 적용 |

D0 배치의 여유 (모두 확인 필요, D1에서 실부재로 재검사):

| 검사 | 값 |
|---|---:|
| 데크 위 SPDB ↔ 마스트 (y) | 5 mm |
| 데크 위 마스트 ↔ Jetson (y) | 18 mm |
| 하부 배터리 슬롯 상면 ↔ 데크 하면 (z) | 9 mm |
| 배터리 슬롯 ↔ 조향 모터 (y) | 15 mm |
| 라이다 스캔 평면 ↔ 스테레오 상단 | 약 11 mm |
| Jetson 상면 z=61 ↔ 라이다 스캔 평면 z=96.3 | 35.3 mm |

**스테레오.** optical을 원점으로 보드 폭을 **y 방향**, 보드 높이를 광축에 수직인 위쪽, 두께를 광축
방향으로 배치한 보수적 중심 블록이다. 광축은 `(cos30°,0,-sin30°)`, 보드 위쪽은 `(sin30°,0,cos30°)`다.
실제 광학 중심의 보드 내 오프셋은 I05에서 보정한다. 이 블록은 마운팅 홀을 정의하지 않는다.

광학 중심 z=70, 지면 z=-273이므로 **높이 343 mm**다. 수직 FOV 50°, 하향 30° 가정에서 지면 교점은
광학 중심 바로 아래에서 **240.2–3920.6 mm 전방**이다(rev.3의 313 mm / 219.2–3577.6 mm를 대체).
지면 교점 거리는 높이에 비례하므로 실제 높이가 확정되면 같은 비율로 다시 계산한다.

**전방 시야 가림.** 개 자세(β=−70°)에서 앞 부채꼴 중심은 x=174.8, 반경 122.5이므로 지면에서
x=52..297 구간을 가릴 수 있다. 근거리 시야가 앞다리에 가리는 것은 4족에서 피할 수 없으므로,
G09에서 **자세·스핀각별 가림 구간과 최대 연속 가림 시간**을 기록한다. 단순 각도 마스킹으로
시야가 복원된다고 주장하지 않는다.

**라이다.** 베이스 z=70, 스캔 평면은 베이스+26.3=96.3 mm(지면 위 369.3 mm)다. rev.3의 64/90.3보다
6 mm 올렸다. 이유는 스테레오 상단(약 z=85.4)이 전방 스캔을 막지 않게 하기 위해서다. 실제 도면과
스테레오 브래킷이 정해지면 이 6 mm를 재확인한다.

포락 교차는 실제 트러스 부재의 교차와 구분해 보고한다. 마스트/Jetson 포락이 겹치면 숨기지 않고
D1 실부재로 해소할 대상이라고 남긴다.
### 9.3 배터리와 배선의 작업 경로

배터리 인출은 기준 자세에서 +y(좌현) 방향으로 슬롯 중심부터 프레임 좌현 끝(y=+175)을 완전히 벗어날 때까지 평행 이동하는 경로다. 1mm 간격 또는 연속 거리 검사로 모터·크로스 리브·케이블·도어와 확인한다. +y 경로가 막히면 임의로 배터리 방향을 바꾸지 않고 G07 FAIL과 첫 충돌 위치를 저장한다. 새 배치 제안은 별도 후보로 작성한다.

rev.2 배선 홀 크기는 아래 **시작 후보**다. 실제 플러그가 통과해야 하는 곳은 케이블 외경만으로 합격시키지 않는다. D0에는 포락만 표시하고 D1의 구조 해석 형상에 실제 홀을 반영한다.

| 위치 | 후보 크기 mm | 개수 | 필수 보완 |
|---|---|---:|---|
| 하부 모터 인출 | 8×4, R1 | 4 | x±45, y=±160에서 조향 모터 장착과 확인 |
| 데크 층간 | 20×8, R1 | 4 | x±50, y±120, 실제 묶음 크기 |
| 배터리 도어 | 12×6, R1 | 1 | 선만 통과하는지 XT60/밸런스 플러그도 통과하는지 명시 |
| 링크 양 끝 | 10×5, R1 | 8 | 정확한 중심·부품면·구조 영향 |
| 요크 | 6×4, R1 | 8 | 회전 시 꼬임·서비스 루프 |
| 마스트 | 10×6, R1 | 1 | LiDAR 플러그·배선 고정 |
| 센서 붐 (전방 x=+65) | 14×4, R1 | 1 | CSI 두 개와 별도 I²C의 통로 |

굽힘 반경 15mm는 케이블 제조사 확인 전 후보값이다. 모든 관절 경로에서 길이·최소 곡률·당김·끼임을 확인한다. 케이블 규격·커넥터 방향·스트레인 릴리프·조립 순서는 I08로 관리한다. 배터리 교체 30초는 이후 실제 작업 시험 목표다.

### 9.4 SPDB와 구조 최적화

전원 분배 PCB를 만드는 방향은 유지한다. D0 포락은 70×90×22mm, 보드 자체 70×90×1.6mm, M3 홀 후보 패턴 62×82mm다. 회로·동박·열·커넥터는 §8.2와 I06이 먼저다. `docs/31-spdb-schematic.md`는 아직 없는 후속 산출물이며 존재한다고 가정하지 않는다.

제너레이티브 설계는 D0의 선행 조건이 아니다. 우선 명시적 파라미터와 동일 하중의 구조 해석을 사용한다. 제너레이티브가 반드시 같은 최적해를 낸다고 주장하지 않는다. Fusion 선형 정적 해석의 이용 조건은 실제 구독/라이선스를 확인한다. [Autodesk 안내](https://www.autodesk.com/support/technical/article/caas/sfdcarticles/sfdcarticles/Do-I-need-Simulation-Extension-to-run-static-stress-simulation-in-Fusion-for-free.h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)

## 10. D0 입력 원천과 데이터 계약

### 10.1 파라미터 JSON

다음 `marc-params` 블록을 그대로 추출해 `params.json`으로 저장한다. 단위는 키의 접미사에
명시한다. 값 없는 제작 입력을 이 JSON에 0으로 추가하지 않는다. 파생값은 §11/§16에서 계산한다.
Fusion 내부 길이 cm에는 mm/10, 각도 rad에는 deg×π/180을 **한 번만** 적용한다.

rev.3에서 바뀐 키: `body.d_leg_long_mm` → `body.track_half_y_mm`, `leg.mid_yoke_extension_mm` 삭제,
`leg.beta_mode_deg`·`leg.beta_limit_deg`·`mass_candidate`·`actuator_catalog` 추가,
`yaw_search_deg` ±110/90 → ±60, `static_margin_target_mm` → 4점/3점 분리,
`mass_upper_candidate_kg` 4.75 → 3.90.

<!-- marc-params:start -->
```json
{
  "schema_version": 2,
  "design_revision": "rev4-D0",
  "status": "CANDIDATE",
  "geometry": {
    "R_tread_mm": 122.5,
    "t_tire_mm": 10.0,
    "b_sector_mm": 20.0,
    "th_tread_deg": 195.0,
    "d_lobe_deg": 45.0,
    "r_lobe_tip_mm": 112.5,
    "profile_step_deg": 0.5,
    "nose_fillet_mm": 0.0,
    "t_rim_mm": 3.0,
    "t_lip_mm": 3.0,
    "h_lip_mm": 12.0,
    "t_web_mm": 2.0,
    "r_hub_mm": 22.0,
    "hub_boss_h_mm": 20.0,
    "t_rib_mm": 2.0,
    "rib_angles_deg": [-135, -90, -45, 0, 45, 90, 135],
    "web_lightening_dia_mm": 30.0,
    "web_lightening_pcd_mm": 120.0,
    "web_lightening_angles_deg": [-112.5, -67.5, -22.5, 22.5, 67.5, 112.5],
    "horn_spigot_dia_mm": 22.4,
    "horn_spigot_depth_mm": 1.5,
    "horn_bolt_pcd_mm": 16.0,
    "horn_bolt_count": 8,
    "horn_insert_pilot_dia_mm": 3.2,
    "horn_insert_depth_mm": 6.0,
    "shaft_relief_dia_mm": 9.0,
    "shaft_relief_depth_mm": 4.0,
    "bearing_seat_dia_mm": 19.0,
    "bearing_seat_depth_mm": 5.0,
    "stub_relief_dia_mm": 11.0,
    "stub_relief_depth_mm": 3.0,
    "link_hole_fraction": 0.0,
    "tire_representation": "envelope_effective_density",
    "hub_interface": "solid_placeholder"
  },
  "leg": {
    "steer_axis_x_mm": 50.0,
    "steer_axis_z_mm": 20.5,
    "stage1_axis_x_mm": 108.0,
    "stage1_axis_z_mm": 0.0,
    "link_a_mm": 90.0,
    "link_b_mm": 110.0,
    "gamma_crank_deg": 25.0,
    "H_reference_mm": 255.0,
    "alpha_abs_reference_deg": 0.0,
    "alpha_park_deg": null,
    "beta_mode_deg": [-25.0, -40.0, -60.0, -70.0, -80.0],
    "beta_limit_deg": [-80.0, -25.0],
    "box_w_mm": 34.0,
    "box_h_mm": 37.0,
    "wall_link_mm": 2.8,
    "wall_yoke_mm": 3.5,
    "clevis_gap_mm": 2.0,
    "clevis_arm_t_mm": 5.0,
    "yaw_search_deg": [-60.0, 60.0],
    "q1_search_deg": [-110.0, 115.0]
  },
  "body": {
    "track_half_y_mm": 160.0,
    "hip_motor_center_x_mm": 36.7,
    "hip_motor_center_z_mm": 3.3,
    "frame_x_mm": 130.0,
    "frame_end_allowance_mm": 30.0,
    "frame_bottom_z_mm": -18.0,
    "frame_beam_w_mm": 12.0,
    "frame_beam_h_mm": 10.0,
    "frame_beam_wall_mm": 2.4,
    "frame_plate_bottom_z_mm": -15.0,
    "frame_plate_t_mm": 2.0,
    "cross_rib_t_mm": 2.4,
    "deck_bottom_z_mm": 28.0,
    "deck_t_mm": 2.0,
    "com_z_candidate_mm": -65.076,
    "camera_pitch_down_deg": 30.0
  },
  "mass_candidate": {
    "total_kg": 3.615,
    "leg_module_g": 665.0,
    "body_and_electronics_g": 955.0,
    "note": "rev.3 D0 6-leg estimate 4.945 kg minus two leg modules; body shrink not credited"
  },
  "actuator_catalog": {
    "MX-28AT":        {"stall_Nm": 2.5, "no_load_rad_s": 5.760, "armature": 0.00521, "mass_g": 77.0},
    "XM430-W350-T":   {"stall_Nm": 4.1, "no_load_rad_s": 4.817, "armature": 0.01749, "mass_g": 82.0},
    "XM430-W210-T":   {"stall_Nm": 3.0, "no_load_rad_s": 8.063, "armature": 0.00633, "mass_g": 82.0}
  },
  "material_preliminary": {
    "PLA_density_g_cm3": 1.18,
    "PLA_E_MPa": 3200.0,
    "PLA_strength_MPa": 48.0,
    "PLA_G_MPa": 1230.0,
    "TPU_effective_density_g_cm3": 0.494
  },
  "validation": {
    "support_tol_mm": 0.01,
    "profile_convergence_mm": 0.05,
    "CAD_axis_distance_mm": 0.05,
    "axis_dot_abs_min": 0.9999,
    "moving_leg_clearance_mm": 10.0,
    "static_margin_4pt_target_mm": 80.0,
    "static_margin_3pt_target_mm": 80.0,
    "mass_upper_candidate_kg": 3.90,
    "design_factor": 1.5,
    "external_loss_factor": 0.75,
    "structural_SF_target": 4.0,
    "sector_deflection_target_mm": 0.53,
    "link_twist_target_deg": 0.10,
    "g_m_s2": 9.81
  }
}
```
<!-- marc-params:end -->

`params.json` 외에 §3–§5의 형상 규칙, §9의 배치 표, §11의 변환 규약도 구현 입력이다. 이를 기계가
읽을 manifest로 옮기고 원문 해시를 함께 기록한다. `userParameters.count` 같은 개수 검사 대신
**요구 키 집합·단위·식·값의 일치**를 검사한다. 배열·문자열·null은 Fusion 길이 파라미터로 만들지
않고 manifest에 보존한다.

`mass_candidate`와 `actuator_catalog`는 **하중·토크 계산 입력**이며 제작 확정값이 아니다.
B05가 실제 질량을 산출하면 `mass_candidate.total_kg`를 갱신하고, 그 값에 의존하는 §3·§6·§7의
모든 표를 다시 생성한다.
### 10.2 산출물과 실행 식별자

후속 구현 파일은 `/Users/hayward_kim/Developer/SCONE/tools/marc/` 아래에 새로 만든다. 산출물은 `/Users/hayward_kim/Developer/SCONE/artifacts/marc/<run_id>/`에 저장한다. `<run_id>`는 `YYYYMMDD_HHMMSS_rev4-D0` 형식이며 이미 있으면 덮어쓰지 않고 새 시간을 사용한다. 다른 체크아웃에서는 저장소 루트만 치환한다.

```text
<run_id>/
  source_manifest.json       원문/입력/도면/도구 해시와 Git 상태
  params.json                위 블록 원본
  inputs.json                I01..I09 근거, 미확인 값은 null
  parts_manifest.json        부품·질량·CoM·관성·좌표
  joints.json                관절 12개, 로컬 축·영점·제한·하드웨어 대응
  allowed_contacts.json      의도된 접촉 쌍만 명시
  calculations.json          프로파일·반력·토크·질량
  checks.json                G00..G11 개별 판정
  paths/                     12축 시간 궤적과 조건
  cad/                       문서 식별자, 네이티브 저장본, STEP
  evidence/                  도면, 단면, 실패 자세, FEA·측정 로그
  meshes/                    export_manifest에 지정된 메시
  handoff.md                 완료·실패·누락·다음 작업
```

검사 결과 한 건의 계약:

```json
{
  "check_id": "G03",
  "status": "NOT_RUN",
  "model_stage": "D0",
  "input_sha256": null,
  "method_version": null,
  "value": null,
  "unit": "mm",
  "limit": 10.0,
  "evidence": [],
  "blocking_inputs": [],
  "reason": "not executed"
}
```

PASS/FAIL에는 실제 입력 해시·방법 버전·근거 경로가 필수다. 예제의 null과 NOT_RUN을 실행 결과처럼 복사하지 않는다. D0의 기하 PASS가 D1의 체결/실물 PASS로 자동 승격되지 않게 `model_stage`를 항상 검사한다.

## 11. 좌표계·관절·번호 규약

### 11.1 몸체와 다리의 기준

몸체 원점은 좌우/전후 중심과 stage-1 축 높이 z=0의 교점이다. **+x 전방, +y 좌현, +z 상방**이다.
세계 좌표와 몸체 좌표가 일치하는 기준 자세에서만 아래 수치를 그대로 읽는다. 몸체가 기울거나
이동하면 전체 몸체 변환을 앞에 곱한다.

**rev.3(+x 우현, +y 전방)에서 축 이름이 바뀌었다.** 이유는 하나다. 이 기구의 **진행 방향은 다리가
뻗는 방향**이고, 4족에서 다리는 앞뒤로 뻗는다. 그러므로 다리가 뻗는 축이 전방(+x)이어야
"앞으로 굴러간다"는 말과 좌표가 일치한다. rev.3에서 "전방 = 몸통 장축(+y)"으로 잡았다가
"조향 없이는 전방 굴림 불가"라는 잘못된 결론이 나왔다. 그 원인을 좌표 정의 단계에서 제거한다.

| 다리 | 위치 | side_x | side_y | 조향축 (x,y,z) mm | 논리 모터 번호: yaw / q1 / q2 |
|---|---|---:|---:|---|---|
| FL | 전방 좌 | +1 | +1 | (+50, +160, 20.5) | M01 / M05 / M09 |
| FR | 전방 우 | +1 | −1 | (+50, −160, 20.5) | M02 / M06 / M10 |
| RL | 후방 좌 | −1 | +1 | (−50, +160, 20.5) | M03 / M07 / M11 |
| RR | 후방 우 | −1 | −1 | (−50, −160, 20.5) | M04 / M08 / M12 |

`side_x`는 다리가 뻗는 방향(전/후)이고 `side_y`는 좌우 위치다. **`u_i`를 만드는 것은 `side_x`뿐이며
`side_y`는 조향축의 y 좌표만 정한다.** 둘을 섞지 않는다.

M번호는 **CAD 논리 식별자**이며 실제 다이나믹셀 ID라고 가정하지 않는다. I01에서 대응을 확인한다.
다리 프레임의 열벡터는 `F_i=[u_i,v_i,w]`, `w=(0,0,1)`이며 `u_i=Rz(yaw_i)*(side_x,0,0)`,
`v_i=Rz(yaw_i)*(0,side_x,0)`다. 두 방향을 함께 뒤집어 후방 다리도 오른손 좌표계를 유지한다.
음의 scale로 솔리드/관성을 미러하지 않는다.

### 11.2 관절과 순기구학의 정확한 정의

| 관절 | 세계/몸체 방향 | 양의 동작 | 영점 |
|---|---|---|---|
| yaw | +z | 위에서 볼 때 반시계 | 링크가 해당 다리의 전/후 바깥으로 향함 |
| q1 | `-v_i` | 링크 기준 +u가 +w 쪽으로 올라감 | 크랭크 첫 구간이 +u |
| q2 | `-v_i` | 부채꼴의 +u 기준점이 +w 쪽으로 회전 | q1=0일 때 §2 프로파일과 일치 |

```text
p_steer = (side_x*steer_axis_x, side_y*track_half_y, steer_axis_z)
p1 = (side_x*steer_axis_x, side_y*track_half_y, stage1_axis_z)
     + (stage1_axis_x-steer_axis_x)*u_i
A = link_a + link_b*cos(gamma)
B = link_b*sin(gamma)
p2 = p1 + (A*cos(q1)-B*sin(q1))*u_i
        + (A*sin(q1)+B*cos(q1))*w
alpha_abs = q1+q2
p_sector(chi,v) = p2 + rho(chi)*cos(chi+alpha_abs)*u_i
                     + v*v_i
                     + rho(chi)*sin(chi+alpha_abs)*w
```

q1의 양의 회전은 앞뒤 다리 모두 발을 위로 올리지만 세계축은 전방 다리 −y, 후방 다리 +y로 다르다.
q2 역시 로컬 −v축이며 부채꼴 평면의 굴림 방향은 ±u다.

**굴림 방향.** `v_axle=-omega x r_contact`로 검사한다. yaw=0에서 `u`는 전방 다리가 +x, 후방 다리가
−x다. **전진(+x)하려면 전방 다리는 q2가 음의 속도, 후방 다리는 q2가 양의 속도**여야 한다.
좌우(y)에 따른 부호 차이는 없다. 네 부채꼴의 장착 헤딩은 모두 같고 조향은 필요 없다.
`joints.json`의 `roll_direction_sign`에 다리별로 `-side_x`를 기록하고 제어기에서 그대로 쓴다.

**스핀 위상 오프셋.** D0 기본은 §7.4의 대각짝 배치다. `spin_phase_offset_deg`는
FL=0, FR=180, RL=180, RR=0이다. 이 값은 파라미터가 아니라 **보행/주행 명령의 초기 조건**이므로
`params.json`이 아닌 `gaits/*.json`에 둔다.

Fusion/MuJoCo의 계층 변환은 다음 순서다: 몸체 → 조향축의 위치와 후방 다리 기본 회전 → yaw(+z) →
stage-1까지의 고정 변환 → q1(로컬 −y) → 크랭크 끝점 고정 변환 `(A,0,B)` → q2(로컬 −y) → 부채꼴.
Euler 부호를 임의로 보정하지 않고 위 순기구학과 좌표를 대조한다.

부품 부착 기준은 다음으로 고정한다. 각 부품의 실제 장착면 오프셋은 I02/I05에 저장하며 회전 계층과
혼동하지 않는다.

| 부품 | 움직임을 따르는 프레임 |
|---|---|
| 하부 프레임·데크·탑재물·yaw 모터 하우징 | 몸체 고정 |
| 요크 #1/#2·stage-1 모터 하우징 | yaw 이후, q1 이전 |
| 크랭크·포크·stage-2 모터 하우징 | yaw와 q1 이후, q2 이전 |
| 부채꼴·타이어·회전 허브 | yaw/q1/q2 이후 |
| 샤프트·베어링 내/외륜·체결류 | I02 조립 단면의 고정/회전 구분; 미확인 시 D1 BLOCKED |

yaw 모터 하우징의 참고 중심은 `(side_x*36.7, side_y*160, 3.3)mm`다. 회전축
`(side_x*50, side_y*160, 20.5)mm`와 다른 점임을 유지하고 실제 CAD에서 확인한다. 모터 형상이
없으면 하우징 중심과 축의 두 마커만 표시한다.
### 11.3 하드웨어 부호표

현재 [하드웨어 정의](/Users/hayward_kim/Developer/SCONE/src/hardware/actuator_control_table.py)는 MX-28AT를 Protocol 1.0/model 29로 사용한다. 이 제어 테이블에는 MX(2.0)의 Drive Mode Reverse가 없다. 기존 펌웨어·ID·EEPROM 설정을 모델링 편의로 변경하지 않는다. [MX-28](https://emanual.robotis.com/docs/en/dxl/mx/mx-28/), [MX-28(2.0)](https://emanual.robotis.com/docs/en/dxl/mx/mx-28-2/)

후속 산출물 `joints.json`과 `docs/variables/joint_sign_table.md`에 다음을 기록한다:

`logical_motor, hardware_id, model_number, firmware, protocol, axis_local, joint_origin, raw_zero, software_sign, radians_per_tick, operating_mode, physical_min_max, evidence`.

기본 변환은 `q_model=software_sign*(raw-raw_zero)*2*pi/4096`이다. 실제 구동 모드에 따른 wrap/multi-turn 범위는 별도 명시한다. 물리 ID·영점·부호가 미확인인 동안 값은 null이고 실물 구동 단계는 BLOCKED다. 문서/CAD 작업 범위만으로 모터를 자동 구동하지 않는다. 실제 캘리브레이션을 수행하는 작업에서는 매 관절의 작은 양의 변위와 이 표의 방향을 대조해 기록한다.

## 12. 물성·관성·MuJoCo 이관

### 12.1 부품 집계

`parts_manifest`가 집계의 원천이다. `_STUDY_` 포락, 숨긴 중복 부품, 원본 참조 조립체는 기본 제외하며, 질량을 가진 payload 대체 블록은 명시적으로 한 번 포함한다. Fusion의 표시 숨김과 질량 제외를 동일하게 취급하지 않는다.

| 물성 종류 | D0 | D1 |
|---|---|---|
| 구조 PLA | §10 예비 벌크 밀도·탄성값 | 실제 출력 방향별 밀도·강도·E/G |
| TPU 외형 | 실효밀도 질량, 강성 미정 | 실제 셀/재료/접촉 시험 |
| 모터·전자부품 | 도면 질량 또는 추정 질량과 상태 | 보유품 리비전·실측 질량 |
| 관성 | 형상 기반 예비값 | 실제 분포/조립 범위와 검증 |

B03는 `MARC_v4_PLA_D0`, `MARC_v4_TPU_envelope_D0` 사용자 재료를 만들고 §10의 밀도를 각 구조/타이어 바디에 명시적으로 배정한다. 같은 이름의 다른 값이 이미 있으면 기존 재료를 수정하지 않고 실행 ID를 붙여 복제한다. `_STUDY_`와 모터 마커는 물성 집계에서 제외한다. 미배정 기본 강철 바디가 부품 목록에 남으면 G05 FAIL이다. D1 재료는 별도 이름과 I04 시험 리비전으로 생성한다.

질량만 일치시키려고 직육면체 밀도를 조정한 모터 모델은 실제 CoM/관성과 동일하지 않다. 제조사 CAD·질량 자료가 없는 축은 관성 검증 상태를 별도로 둔다.

### 12.2 Fusion 관성 변환

`getXYZMomentsOfInertia()`는 세계 원점 기준, kg·cm² 단위다. 결과 성공 플래그와 성분 순서를 확인하고 **×1e-4**로 kg·m²로 바꾼다. [Autodesk API](https://help.autodesk.com/cloudhelp/ENU/Fusion-360-API/files/PhysicalProperties_getXYZMomentsOfInertia.htm)

1. Python 반환 순서는 `(success,xx,yy,zz,xy,yz,xz)`다. API 설명만으로 교차 성분 부호를 단정하지 않고 아래 B05 시험으로 adapter를 결정한다. `xy`가 교차적분 `integral(x*y dm)`이면 텐서의 비대각 성분은 그 음수다.
2. 별도 스터디에서 균일 직육면체 XYZ=20×30×40mm, 밀도 1.18g/cm³를 만든다. 중심 원점/무회전 경우와 중심 c=(100,200,300)mm, 회전 `Rz(30deg)*Ry(20deg)`인 경우를 검사한다. 분석해는 m=0.02832kg, `I_COM_local=m/12*diag(0.03^2+0.04^2,0.02^2+0.04^2,0.02^2+0.03^2)`, `I_origin=R*I_COM_local*R^T+m*((c·c)*Id-c*c^T)`이며 c는 m로 넣는다. 반환 비대각을 그대로/음수로 넣은 두 adapter 중 전 성분이 `max(1e-10kg·m²,1e-5*max_abs(I_expected))` 이내인 하나만 채택한다. 둘 다 실패하거나 둘 다 통과하면 G05 FAIL이다. 선택 결과와 Fusion 버전을 저장하고 실제 바디와 occurrence의 좌표 변환도 같은 시험으로 검증한다.
3. COM 벡터 c를 m로 변환한 후 `I_COM=I_origin-m*((c·c)*Id-c*c^T)`로 옮긴다.
4. 실제 회전축 위의 점 a와 단위 방향 n에 대해 `d=c-a`, `I_axis=n^T*(I_COM+m*((d·d)*Id-d*d^T))*n`을 계산한다.
5. MuJoCo에는 부품 **COM 기준, 해당 로컬 프레임**의 관성을 넣는다. 위 I_axis를 그대로 body inertia로 넣어 armature와 이중 집계하지 않는다.

물성 API의 질량은 kg, 체적은 cm³, 밀도는 kg/cm³다. 문서의 1.18g/cm³를 해당 API 단위로 비교하면 0.00118kg/cm³이며, 소재 편집 API가 다른 단위를 요구하면 그 스키마대로 변환한다. 텐서의 대칭성·양의 고유값·주관성의 삼각 부등식도 확인한다. [물성 API 단위](https://help.autodesk.com/cloudhelp/ENU/Fusion-360-API/files/PhysicalProperties.htm)

스핀 관성의 부품 범위는 **회전하는 PLA 부채꼴+TPU+회전 허브/스터브/체결류**다. 고정 모터 케이스와 포크는 제외한다. 후보 목표 2.2e-3kg·m²와 비교할 때 이 범위를 함께 표기한다. `Izz`라는 이름으로 축을 생략하지 않는다.

### 12.3 시뮬레이션 파일과 검증

MARC 자산은 `/Users/hayward_kim/Developer/SCONE/src/assets/marc/<model_revision>/`에 새로 둔다. 기존 `src/assets/model.xml`, 기존 메시 및 v2 제어기를 덮어쓰지 않는다. 현재 모델과 연결하기 위한 어댑터는 별도 변경 작업으로 취급한다.

- 메시 개수 10개를 강제하지 않는다. `export_manifest.json`에 부품별 파일·좌표·단위·좌우 인스턴스·시각/충돌 역할을 명시한다.
- 열린 부채꼴을 단일 convex hull 충돌체로 바꿔 개구를 메우지 않는다. 충돌 분할은 실제 개구·로브·팁을 보존하고 기준 접촉점/높이와 비교한다.
- 조인트 12개, 위치·축·영점, 물리 하드스톱, 모터 타입·전압·토크–속도 모델을 명시한다.
- 기존 armature 0.00521/0.01749/0.00633kg·m²는 모터별 **초기 추정값**으로 보존할 수 있다. 실측 확정값으로 부르지 않는다.
- damping/frictionloss는 기존 DC 모터 손실과 중복시키지 않는다. 무전원 마찰·추가 베어링·백래시 시험이 없으면 0은 이상 모델의 초기 가정이다.
- `kd=2*sqrt(kp*J_eq)`는 단순 1자유도 초기값이다. 실제 결합·제어 주기·포화에서 안정성을 검증한다.
- 횡변형·비틀림·자유 백래시를 stage-2 축의 스프링 하나로 합치지 않는다. 측정된 변위 방향의 추가 자유도/탄성을 모델링하고 강체 기준과 비교한다.
- SCONE v2 PPO 체크포인트를 MARC v4에 그대로 재개하지 않는다. 다리 수·관절 수가 달라 관측·액션 차원부터 맞지 않는다. 관측·액션·조인트·물성·제어 프로파일 호환 검사가 선행한다.

## 13. Fusion 접근과 실행 환경

현재 저장소에 `/Users/hayward_kim/Developer/SCONE/tools/fmcp.py`가 있다. 이 파일은 import 시에도 `main()`을 실행해 접속하므로 순수 계산 코드에서 import하지 않는다. localhost 서버의 현재 가용성은 이번 문서 개정에서 확인하지 않았다.

```bash
cd /Users/hayward_kim/Developer/SCONE
/usr/bin/python3 tools/fmcp.py list
```

이 명령은 도구 목록 확인용이다. 반환된 실제 스키마를 저장하고 그 스키마로 문서 목록/활성 문서를 읽는다. 과거 `fusion_mcp_read` 호출 인자를 검증 없이 재사용하지 않는다. 서버가 없으면 CAD 관련 단계만 BLOCKED로 기록하고 순수 계산·입력 자료 정리를 계속한다.

후속 스크립트가 실제 작성되고 정적 검사까지 통과한 뒤에만 다음 형식을 사용한다.

```bash
/usr/bin/python3 tools/fmcp.py script tools/marc/build_03_sector.py
```

- `127.0.0.1:27182`는 같은 Mac의 localhost다. VM/원격 셸의 localhost와 혼동하지 않는다.
- 문서 생성 후 document ID와 이름을 확인하고 각 변경 전 대상 ID가 같은지 검사한다. 이름이 같다고 기존 문서를 자동 지우지 않는다.
- 스크립트는 manifest에 저장한 자기 소유 component ID만 갱신한다. 재실행 시 조인트·바디를 중복 생성하지 않는다.
- 비ASCII 전송 문제가 발생하면 ASCII JSON/식별자로 전달하고 원문/응답을 비교한다. 화면에 정상 표시됐다는 이유만으로 코드 전송 성공을 가정하지 않는다.
- volume/area/referencePlane API 예외는 개별 대상과 메시지를 기록한다. 실패한 부품을 질량 0으로 넣고 검사를 통과시키지 않는다.
- 현재 도구 스키마가 필요한 API를 제공하지 않으면 이름을 추측해 호출하지 않는다. 로컬 Fusion 스크립트 실행 방식으로 전환한 사유와 방법을 기록한다.

## 14. 다른 에이전트의 실행 순서

### 14.1 스크립트 작성과 관문

아래 파일은 **앞으로 `tools/marc/`에 구현할 작업 목록**이다. 이 문서 개정만으로 파일이 생긴 것은
아니다. 같은 작업을 수행하는 기존 코드가 있으면 원본을 변경하지 않고 버전/해시를 고정해 재사용한다.
기존 `tools/v3/`는 6족 전제이므로 새 경로에 작성한다.

| 단계 | 작성할 파일 | 입력/작업 | 완료 산출물·관문 |
|---|---|---|---|
| B00 | `prepare_run.py` | 원문 해시, Git 상태, §10 추출, I01..I09 초기화 | source_manifest/params/inputs, G00 |
| B01 | `calc_profile.py` | §2 다각형·지지점·수렴 검사 | calculations의 profile, G01 기하 |
| B02 | `collect_parts.py` | I01–I09 기존 자료 수집, 부품 도면·단위·출처 저장 | parts/inputs; 없는 항목 null |
| B03 | `build_03_sector.py` | 새 D0 문서, §2/§3 PLA·TPU 생성 | 부품별 유효 솔리드·체적, G01 |
| B04 | `build_04_leg_body.py` | §4/§5/§9 D0 링크·포락·몸체(종 리브 포함) | 중복 없는 부품 ID, D0 미완성 체결 명시 |
| B05 | `check_05_properties.py` | API 단위/관성 회귀, 명시 부품 집계 | mass/CoM/inertia, G05 |
| B06 | `build_06_assembly.py` | §11의 **4다리·12관절**·탑재물 | joints/parts 좌표, G02 |
| B07 | `resolve_07_interfaces.py` | I02/I03/I04 확보 후 D1 허브·포크·체결·타이어 정의 | 단면·가공도, G06의 선행 조건 |
| B08 | `build_08_paths.py` | 아래 D0 진단 경로와 이후 I09 보행 궤적 | paths와 경로별 상태 |
| B09 | `check_09_clearance.py` | §7 격자/연속 경로, 앞뒤 여유, 교체/배선/센서 | G03/G07, 실패 자세 |
| B10 | `calc_10_loads.py` | 실제 접점·CoM·부품 중량·I07, **yaw 재배치 마진 탐색** | 반력/토크/정지 후보, G04 |
| B11 | `validate_11_structure.py` | D1 최종 형상·I04·LC01..08 | FEA/시편/조립체 검증, G06 |
| B12 | `validate_12_power_sensors.py` | I05/I06/I07 실제 조건과 시험 | G08/G09 |
| B13 | `export_13_model.py` | 부품 명세·관절·충돌 분할, §12 | 별도 RG 자산, G10 |
| B14 | `write_14_handoff.py` | 모든 관문 결과 | checks와 handoff, D0/D1/RELEASE 상태 |

B00→B01은 Fusion 없이 실행한다. B02 자료 수집은 B01/B03과 독립적으로 진행 가능하다. B07에 필요한
실물 자료가 없어도 D0의 B04–B06과 기하 진단은 진행한다. **B14는 실패/누락이 있어도 작성**해
다음 작업이 정확히 남도록 한다.

B13은 D0에서도 B05/B06 결과를 받아 먼저 실행할 수 있다. 질량·관성이 빠진 경우 시각/기구학 자산만
`kinematic_only=true`로 내보내고 동역학·학습용 모델로 표시하지 않는다. 입력이 갖춰지면 D0의 예비
동역학 모델로 구동 가능성을 먼저 검사한다. D1 형상·물성이 바뀐 뒤 B05/B06/B09/B10/B13을 다시
실행한다. B11/B12의 실물 시험을 기다리느라 가능한 시뮬레이션 검사를 미루지 않는다.

### 14.2 D0 진단 경로의 정확한 정의

경로 배열의 관절 순서는 `[M01..M04, M05..M08, M09..M12]` = `[yaw FL,FR,RL,RR, q1 FL,FR,RL,RR,
q2 FL,FR,RL,RR]`, 단위 rad, 시간 s다. 초기 자세는 §6의 yaw=0, q1 기준값, q2=−q1이다.
보간은 구간마다 `f(t)=3*s^2-2*s^3`, `s=(t-t0)/(t1-t0)`를 사용한다. 초기 관통이 있으면 경로를
실행하지 않고 시작 자세 FAIL을 기록한다.

| 경로 ID | 구간 | 목적 |
|---|---|---|
| P00 | 0..1s 초기 자세 유지 | 좌표/지지점/정적 간섭 |
| P01-Li | 0..2s 선택 다리 q1을 기준+20°로; q2=−q1 유지. 2..4s yaw 0→+60°. 4..8s +60→−60°. 8..10s −60→0°. 10..12s 초기 복귀 | 다리 4개 독립 스윙/조향 진단 |
| P02-pair | 6쌍 전체에 대해 두 다리를 P01처럼 든 뒤, 2..4s yaw 0→(+45,−45)°, 4..8s→(−45,+45)°, 8..10s→(0,0), 10..12s 복귀. **같은 쪽 앞뒤 쌍은 (+60,−60)까지 확장** | 조향 중심 이동 반례, 앞뒤 부채꼴 간섭 |
| **P03-crawl-Li** | 0..2s 지지 3다리를 §7.3 표의 yaw로 이동. 2..4s 선택 다리 들기. 4..6s 내리기. 6..8s yaw 복귀 | **정적 크롤 1스텝의 간섭·마진 동시 검증** |
| **P04-beta** | 0..4s 네 다리 beta −50.406→−70°(개 자세), 4..6s 유지, 6..10s −70→−25°(스파이더), 10..14s 복귀 | 자세 전환 전 구간의 앞뒤 여유·지면 관통 |
| P05-Li | 단일 다리 스터디의 지면 z=0, 축 중심 (0,0,R_tread+10mm). q1은 기준값, yaw=0을 유지하고 q2 0→360° 8s | 1회전 접지 형상·포크 간섭 |
| **P06-phase** | 네 다리 q2를 §7.4 대각짝 오프셋(0/180/180/0)으로 두고 동시에 0→720° 12s | 굴림 위상 배치의 접지·상하동요 확인 |

P01의 +20°가 실제 다리를 충분히 띄우는지 접촉 계산으로 확인한다. 지면을 계속 관통하면 실패로
남기고 임의 높이를 추가하지 않는다. P04에서 `beta=-80°` 부근의 앞뒤 여유 38.83 mm를 실제 형상으로
확인한다. 이 경로들은 **진단용**이며 지지 안정성이 검증된 보행 명령이 아니다. 시뮬레이션/실물
동적 실행은 해당 관문 통과 뒤 별도 수행한다.
### 14.3 결정이 필요한 경우의 처리

| 상황 | 정해진 처리 |
|---|---|
| CAD 형상 생성 실패 | 실패 feature와 입력 저장; 단계 FAIL. 자동 형상 변경 금지 |
| 측정/도면 없음 | I번호·필드·확보 경로를 기록, 종속 관문 BLOCKED |
| 간섭·토크·질량 목표 실패 | 실패 후보 보존, 위반량과 민감도 표 작성; 임의 목표 완화 금지 |
| 기존 파일/문서가 이미 있음 | 소유 manifest와 해시 확인; 자기 이전 산출물만 갱신, 나머지는 새 실행 경로 |
| 단위/좌표 불일치 | 전체 변환을 §11/§12로 추적해 수정; 임의 sign/scale 보정 금지 |
| 입력이 충분한 루틴 구현 선택 | 이 명세의 데이터 계약과 검사를 만족하는 코드로 구현하고 버전 기록 |

새 설계 후보가 필요한 경우 기존 D0를 덮어쓰지 않고 `candidate_id`, 바꾼 파라미터, 변경 이유, 재실행할 관문을 명시한다. 문서에 없는 물리 치수·성능 한계를 확정할 결정은 필요한 근거/선택을 모아 한 번에 정리한다. 이미 실행 가능한 계산을 끝내기 전에 단순 구현 취향을 질문하지 않는다.

### 14.4 구현 진입점과 재실행 규칙

모든 B단계 구현은 `run(ctx)`를 진입점으로 제공한다. ctx에는 `repo_root`, `run_dir`, `stage`, `document_id`, `params_sha256`를 넣는다. `repo_root/run_dir`는 절대 경로, stage는 D0 또는 D1, document_id는 최초 생성 전만 null이다. 설정을 전역의 `active_run` 파일에 공유하지 않는다.

- B00는 로컬 CLI로 `--repo-root`와 `--run-dir`를 받으며 새 실행 디렉터리를 만든다. 나머지 순수 계산 단계 B01/B02/B08/B10/B14는 `--run-dir`에서 ctx를 읽는다. source_manifest의 원문·입력 해시가 달라지면 새 실행 디렉터리를 요구한다.
- Fusion 단계 B03–B07/B09/B13는 B00가 만든 실행 디렉터리의 `cad/dispatch_Bxx.py`로 호출한다. dispatcher는 해당 실행의 ctx를 명시적으로 넣고 버전이 고정된 구현의 `run(ctx)`를 호출한다. `fmcp.py script`에 전달할 파일은 이 dispatcher다. Fusion의 현재 작업 디렉터리나 `__file__`이 저장소를 가리킨다고 가정하지 않는다.
- B03의 최초 document 생성은 새 ID를 반환하고 ctx에 저장한다. 나머지 Fusion 변경은 이 ID를 확인한 뒤 실행한다. 스터디용 관성 시험은 별도 문서에서 수행하며 로봇 문서 ID를 덮어쓰지 않는다.
- B11/B12는 해석/측정 산출물을 읽어 판정하는 도구다. 계산 도구 호출만으로 물리 시험을 자동 실행하거나 결과를 생성하지 않는다. 시험 결과가 없으면 해당 입력을 BLOCKED로 반환한다.
- 각 단계는 `{step_id,status,outputs,checks,blocking_inputs,error}`를 반환한다. Python 예외/API 실패가 있으면 status=FAIL이며 출력 파일이 생겼다는 이유로 성공으로 바꾸지 않는다.
- 산출물은 임시 파일에 쓴 뒤 유효성 확인 후 교체한다. 실패한 실행의 마지막 정상 산출물은 보존하되, 새 입력의 성공 결과처럼 재사용하지 않는다.

§13의 단순 `fmcp.py script` 예시는 전송 형식 설명이다. 실제 후속 실행 명령은 생성된 dispatcher의 절대 경로로 기록한다. 이 진입점 계약은 구현할 명세이며, 현재 실행 가능한 B00–B14 파일이 있다는 뜻이 아니다.

## 15. 검증 관문과 완료 조건

### 15.1 관문 표

| ID | 검사 | PASS 조건 | 부족/실패 시 |
|---|---|---|---|
| G00 | 입력·재현성 | JSON 유효, 필수 키/단위 일치, 원문·도구·입력 해시 기록, 기존 변경 보존 | 데이터 정리부터 수정 |
| G01 | 프로파일·솔리드 | 정의된 양의 두께, 유효 솔리드, 수렴<0.05mm, D0 heave 33.2477±0.1mm / 팁 현 길이 136.9713±0.1mm | B01/B03 실패 위치 수정 |
| G02 | 좌표·관절 | §11 FK와 CAD 축/원점 거리≤0.05mm, 방향 내적≥0.9999, 양의 방향 **12/12** 일치, 굴림 방향 부호 `-side_x` 확인 | 영점/변환 추적, 하드웨어 미확인 별도 BLOCKED |
| G03 | 경로·간섭 | 허용 경로 전 구간에 미허용 교차 0, 다리 비접촉 부품 여유≥10mm, **앞뒤 부채꼴 중심거리≥255mm**, 상세 접합 쌍은 지정 공차 | 부품 쌍/12축 자세/시간 기록 |
| G04 | 지지·구동 | 모든 허용 동작에서 반력/마찰 평형, **4점 마진≥80mm, 3점(yaw 재배치 후) 마진≥80mm**, 실제 토크–속도/전류/열 한계 내 | I07/I09 없으면 운전 판정 BLOCKED |
| G05 | 질량·관성 | 누락/중복 0, 총질량≤**3.90kg** 후보 목표, 스핀 관성≤2.2e-3kg·m² 후보 목표, CoM 범위 기록 | 예비/실측 등급 구분, 초과량 기록 |
| G06 | 조립·구조·제작 | 실제 인터페이스 성립, 최종 형상의 LC01..08, SF≥4, LC03 판 변위≤0.53mm/링크 비틀림≤0.10°, 제작 공차 달성 | D0 포락/예비 E로 제작 PASS 금지 |
| G07 | 탑재·배선·교체 | 실제 플러그/배선/도어 경로 간섭 0, 규격 굽힘·장력 이내, 고정부 제작 가능 | 해당 I05/I08 또는 배치 수정 |
| G08 | 전원 | 정격표 완성, 모든 시험에서 부품 전압/전류/온도/차단 조건 만족, 역전력 처리 확인 | I06/I07 미정이면 BLOCKED |
| G09 | 센서 | 실제 보정/동기 오차/**앞다리 가림 구간**/이동 중 깊이·탐지 성능이 I09 요구 만족 | 요구/측정이 없으면 수치 날조 없이 BLOCKED |
| G10 | 시뮬레이션 | 모델 로드, **12축** 순서/부호, 접지·질량·관성 일치, 무입력/단축/허용 경로 검사, 비유한 값 없음 | 별도 RG 자산만 수정, SCONE v2 성능 승계 금지 |
| **G11** | **자세 모드 한계** | `beta` 범위 −80..−25° 강제, 3점 지지는 `beta<=-40°`에서만, 트롯은 `beta<=-60°`에서만, 같은 쪽 yaw 벌림 ≤±60° | 제어기·경로 생성기에 하드 제약으로 반영 |

G01의 수학적 기준값은 D0 프로파일 재현성 검사다. D1 필렛/타이어를 바꾸면 D0 값과의 차이를
기록하고 **D1 자체의 목표 heave·throat 및 I09 계단 성능**으로 평가한다. D0 숫자에 맞추기 위해
CAD를 조정하지 않는다.

G11은 rev.4에서 새로 생긴 관문이다. 4족은 6족과 달리 자세에 따라 토크·간섭·안정성이 모두
한계선에 닿으므로, 이 네 가지 제약을 코드에서 강제하지 않으면 계산상 PASS인 설계가 실제로는
stall 초과나 앞뒤 다리 충돌을 낸다.
### 15.2 후보 목표와 미확정 요구

질량 **3.90kg**, 4점 정적 마진 80mm, **3점(yaw 재배치 후) 정적 마진 80mm**, SF4, 판 변위 0.53mm,
링크 비틀림 0.10°, 스핀 관성 2.2e-3kg·m²가 rev.4의 설계 목표다. 질량 목표만 4족 전환에 맞춰
4.75kg에서 내렸고 나머지는 rev.2에서 계승한 값 그대로다. 이 문서는 목표를 몰래 완화하지 않는다.
서로 양립하지 않으면 실패를 근거로 새 목표/후보를 제시한다.

추가로 rev.4는 **자세 모드별 한계**를 목표에 포함한다: `beta` −80..−25°, 3점 지지는 `beta<=-40°`,
트롯은 `beta<=-60°`, 같은 쪽 앞뒤 yaw 벌림 ±60°. 이 네 가지는 계산으로 확인한 하드 제약이며
G11에서 판정한다.

출력 강도·온도·변형 허용치는 소재/부품 자료와 시험으로 뒷받침해야 한다. 크리프는 실제 정지 하중에서 24시간 시험을 수행하되 허용 영구변형·주위 온도·측정 오차는 I04/I09에서 먼저 고정한다. 허용치 없는 시험은 측정 결과이며 PASS가 아니다.

### 15.3 단계별 완료 판정

- **D0 구현 완료:** B00/B01/B03–B06 산출물이 존재하고 G00/G01/G02의 CAD 부분이 PASS. G03/G05에서 실행 가능한 진단을 수행하고 세부 항목별 PASS/FAIL/BLOCKED를 모두 기록한다. 물리 인터페이스·질량이 빠졌으면 전체 조립/질량 관문은 BLOCKED이며 부분 결과만 보고한다.
- **D1 설계 검증 완료:** I01–I09의 해당 필수 입력을 확보하고 G00–G09와 G11의 설계/시험 관문을 실제 최종 부품 리비전에서 통과한다. 실물 시험을 못 했으면 그 부분은 BLOCKED로 남겨 완료라고 부르지 않는다.
- **RELEASE:** D1 조건, G10, 제작 도면·슬라이서 설정·부품 BOM·조립 순서·전원 회로가 같은 리비전으로 묶여 있고 실패/누락 관문이 없다.

후속 에이전트는 임의로 PASS를 선언하지 않고 `handoff.md`에 실제 달성한 단계와 남은 작업을 기록한다.

## 16. 도구 현황과 독립 계산 예제

### 16.1 현재 존재하는 파일

| 파일 | 상태와 사용 제한 |
|---|---|
| `/Users/hayward_kim/Developer/SCONE/tools/fmcp.py` | 기존 Fusion 클라이언트. 현재 접속 상태와 서버 스키마는 재확인 |
| `/Users/hayward_kim/Developer/SCONE/tools/sector_geom.py` | 기존 기하 탐색 참고. 명칭·회전당 이동거리·프로파일을 rev.3와 대조 후 재사용 |
| `/Users/hayward_kim/Developer/SCONE/tools/sector_struct.py` | 기존 단면 예비식. 최종 로브/허브/구멍 구조 검증 대체 불가 |
| `/Users/hayward_kim/Developer/SCONE/tools/sector_mass.py` | 이전 형상 질량 참고. D0/D1의 원천 아님 |
| `/Users/hayward_kim/Developer/SCONE/tools/leg_torque.py` | rev.2의 잘못된 정지 접점 가정을 포함한 참고 코드. 출력값을 새 판정에 사용 금지 |
| `/Users/hayward_kim/Developer/SCONE/tools/mass_budget.py` | 알루미늄·Orin·RPLIDAR·OAK 계열 rev.1 BOM. rev.3 계산으로 사용 금지 |
| `/Users/hayward_kim/Developer/SCONE/tools/frame_torsion.py` | 현재 없음. 존재하는 파일로 호출 금지 |
| `/Users/hayward_kim/Developer/SCONE/tools/marc/` | B00–B14를 앞으로 작성할 경로. 이번 개정에서는 생성하지 않음. 기존 `tools/v3/`는 6족 전제이므로 재사용하지 않음 |

[rev.2 독립 계산 결과](/Users/hayward_kim/Developer/SCONE/tmp/v3review/rev2-audit-20260909/checks.json)는 원문 해시 `fc39853166a5bbb7ad6a6d8e148d60e47f8ff53c899ac27a45c5884264229256`에 대응한다. 그때의 `recalculate.py`는 rev.2 문서 구조를 읽으므로 변경된 rev.3에 그대로 실행하지 않는다. 과거 증거 JSON을 새 결과로 덮어쓰지 않는다.

### 16.2 Fusion 없이 실행하는 기준 계산

아래 `marc-reference-python` 블록은 Python 표준 라이브러리만 사용한다. 저장소 루트에서
실행한다. 문서/하드웨어/CAD를 수정하지 않고 결과 JSON을 표준 출력한다. B00는 시작/끝 HTML 마커
사이에서 행 시작의 여는/닫는 코드 펜스를 제거해 추출하고 해시를 기록한다. 코드 문자열 안의 백틱을
닫는 펜스로 해석하지 않는다. 아래 assertion은 **수학·좌표 회귀 시험**이며 전체 설계 합격을
선언하지 않는다.

이 블록이 검증하는 것: 크랭크 등가 링크, 접지 프로파일 수렴과 heave, 회전당 이동거리 분해,
4족 자세·토크 표, 부채꼴 면외 단면, 4점/3점 정적 마진, yaw 재배치 크롤 해, 굴림 위상 5가지의
상하동요·기울기·접지 수, 계단 걸기 토크, 조향 토크.

<!-- marc-reference-python:start -->
```python
from pathlib import Path
import hashlib, json, math, itertools

root = Path.cwd()
doc = root / "docs/30-scone-v3-design-plan.md"
source = doc.read_text(encoding="utf-8")
block = source.split("<!-- marc-params:start -->", 1)[1]
block = block.split("<!-- marc-params:end -->", 1)[0]
p = json.loads(block.split("```json", 1)[1].split("```", 1)[0])
g, leg, body = p["geometry"], p["leg"], p["body"]
val, mat = p["validation"], p["material_preliminary"]
rad, deg = math.radians, math.degrees

# ---- 1. crank -> effective link
A = leg["link_a_mm"] + leg["link_b_mm"]*math.cos(rad(leg["gamma_crank_deg"]))
B = leg["link_b_mm"]*math.sin(rad(leg["gamma_crank_deg"]))
L = math.hypot(A, B); phi = math.atan2(B, A)
ground = body["frame_bottom_z_mm"] - leg["H_reference_mm"]
axle_z = ground + g["R_tread_mm"]
beta0 = math.asin((axle_z-leg["stage1_axis_z_mm"])/L)
q1_0 = beta0 - phi
q2_0 = rad(leg["alpha_abs_reference_deg"]) - q1_0
arm0 = L*math.cos(beta0)

# ---- 2. profile / support function
half_tread = g["th_tread_deg"]/2
half_material = half_tread + g["d_lobe_deg"]
assert half_material < 180 and g["d_lobe_deg"] > 0
def rho(c):
    e = max(abs(c)-half_tread, 0.0)
    return g["R_tread_mm"] - (g["R_tread_mm"]-g["r_lobe_tip_mm"])*e/g["d_lobe_deg"]
def scan(step):
    n = round(2*half_material/step)
    chi = sorted(set([-half_material+2*half_material*i/n for i in range(n+1)]+[-half_tread, half_tread]))
    pts = [(rho(c)*math.cos(rad(c)), rho(c)*math.sin(rad(c))) for c in chi]
    m = round(360/step); hs = []
    for j in range(m):
        a = 2*math.pi*j/m; ca, sa = math.cos(a), math.sin(a)
        hs.append(-min(x*sa+z*ca for x, z in pts))
    return hs
def summ(hs):
    m = len(hs)
    return {"heave_mm": max(hs)-min(hs), "h_max_mm": max(hs), "h_min_mm": min(hs),
            "ideal_distance_integral_mm": sum(hs)*2*math.pi/m}
coarse, fine = scan(g["profile_step_deg"]), scan(g["profile_step_deg"]/2)
prof_c, prof_f = summ(coarse), summ(fine)
tip_chord = 2*g["r_lobe_tip_mm"]*math.sin(rad(180-half_material))
roll_only = 2*math.pi*g["R_tread_mm"]*(g["th_tread_deg"]/360.0)

# ---- 3. loads
G = val["g_m_s2"]; m_tot = p["mass_candidate"]["total_kg"]; Wt = m_tot*G
W = {"4pt": Wt/4, "3pt": Wt/3, "trot2": Wt/2}
kf = val["design_factor"]/val["external_loss_factor"]

# ---- 4. posture table
def posture(bdeg):
    b = rad(bdeg); az = L*math.sin(b); gr = az-g["R_tread_mm"]
    a = L*math.cos(b)
    return {"beta_deg": bdeg, "q1_deg": deg(b-phi), "H_mm": body["frame_bottom_z_mm"]-gr,
            "arm_mm": a, "wheelbase_mm": 2*(leg["stage1_axis_x_mm"]+a),
            "foot_x_mm": leg["stage1_axis_x_mm"]+a, "ground_z_mm": gr,
            "tau_3pt_Nm": kf*W["3pt"]*a/1000, "tau_4pt_Nm": kf*W["4pt"]*a/1000,
            "tau_trot_Nm": kf*W["trot2"]*a/1000,
            "front_rear_gap_mm": 2*(leg["stage1_axis_x_mm"]+a)-2*g["R_tread_mm"]}
betas = sorted(set(leg["beta_mode_deg"]+[deg(beta0)]))
postures = [posture(bd) for bd in betas]
stall1 = p["actuator_catalog"]["XM430-W350-T"]["stall_Nm"]
for s in postures:
    for k in ("3pt","4pt","trot"):
        s["pct_"+k] = 100*s["tau_%s_Nm"%k]/stall1

# ---- 5. stride / speed
def stride(bdeg, sweep_deg=15.0):
    b = rad(bdeg); return {"beta_deg": bdeg, "dx_dbeta_mm_per_rad": L*abs(math.sin(b)),
                           "stride_mm": 2*L*abs(math.sin(b))*rad(sweep_deg)}
strides = [stride(x) for x in (-50.406090, -70.0, -80.0)]
w210 = p["actuator_catalog"]["XM430-W210-T"]
dist_rev = prof_f["ideal_distance_integral_mm"]
roll_speed_max = dist_rev/1000*(w210["no_load_rad_s"]/(2*math.pi))

# ---- 6. sector out-of-plane section (rim + two lips), b = axial width
b_s, t_r, t_l, h_l = g["b_sector_mm"], g["t_rim_mm"], g["t_lip_mm"], g["h_lip_mm"]
I_sec = (t_r*b_s**3)/12 + 2*(h_l*t_l**3/12 + h_l*t_l*((b_s-t_l)/2)**2)
Z_sec = I_sec/(b_s/2)
Lm = g["R_tread_mm"]-g["r_hub_mm"]          # moment arm, load at tread
Ld = g["r_lobe_tip_mm"]-g["r_hub_mm"]       # plate cantilever length
sigma5 = 5*W["3pt"]*Lm/Z_sec
SF5 = mat["PLA_strength_MPa"]/sigma5
defl3 = 3*W["3pt"]*Ld**3/(3*mat["PLA_E_MPa"]*I_sec)

# ---- 7. feet, support polygon, static margins
T2 = body["track_half_y_mm"]
def feet_at(a):
    return {"FL": (leg["stage1_axis_x_mm"]+a,  T2), "FR": (leg["stage1_axis_x_mm"]+a, -T2),
            "RL": (-(leg["stage1_axis_x_mm"]+a), T2), "RR": (-(leg["stage1_axis_x_mm"]+a), -T2)}
def margin(poly, com=(0.0, 0.0)):
    n = len(poly); best = float("inf"); inside = True
    cx, cy = com
    area2 = sum(poly[i][0]*poly[(i+1) % n][1]-poly[(i+1) % n][0]*poly[i][1] for i in range(n))
    sgn = 1.0 if area2 >= 0 else -1.0
    for i in range(n):
        x1, y1 = poly[i]; x2, y2 = poly[(i+1) % n]
        ex, ey = x2-x1, y2-y1; ln = math.hypot(ex, ey)
        cr = sgn*(ex*(cy-y1)-ey*(cx-x1))/ln
        if cr < 0: inside = False
        best = min(best, abs(cr))
    return best if inside else -best
F = feet_at(arm0)
poly4 = [F["FL"], F["FR"], F["RR"], F["RL"]]          # CCW-ish rectangle
m4 = margin(poly4)
tri = {}
for lift in ("FL", "FR", "RL", "RR"):
    keys = [k for k in ("FL", "FR", "RR", "RL") if k != lift]
    tri[lift] = margin([F[k] for k in keys])
h_com = body["com_z_candidate_mm"]-ground
tip_roll = deg(math.atan2(T2, h_com))
tip_pitch = deg(math.atan2(leg["stage1_axis_x_mm"]+arm0, h_com))
def roll_for_margin(mm): return deg(math.atan2(mm, h_com))

# ---- 7b. static crawl: re-yaw the three support legs
reach = leg["stage1_axis_x_mm"]-leg["steer_axis_x_mm"]+arm0
STEER = {"FL": (leg["steer_axis_x_mm"], T2), "FR": (leg["steer_axis_x_mm"], -T2),
         "RL": (-leg["steer_axis_x_mm"], T2), "RR": (-leg["steer_axis_x_mm"], -T2)}
SGN = {"FL": 1, "FR": 1, "RL": -1, "RR": -1}
def foot_yaw(k, psi_deg):
    s = SGN[k]; a = rad(psi_deg)
    return (STEER[k][0]+s*reach*math.cos(a), STEER[k][1]+s*reach*math.sin(a))
sep_min = 2*g["R_tread_mm"]+val["moving_leg_clearance_mm"]
same_side_yaw_limit = None
for a in range(0, 91):
    if math.dist(foot_yaw("FL", a), foot_yaw("RL", -a)) < sep_min:
        same_side_yaw_limit = a-1; break
lim = int(leg["yaw_search_deg"][1])
crawl = {}
for lift in ("FL", "FR", "RL", "RR"):
    keys = [k for k in ("FL", "FR", "RR", "RL") if k != lift]
    best = None
    for a in range(-lim, lim+1, 5):
        f0 = foot_yaw(keys[0], a)
        for b_ in range(-lim, lim+1, 5):
            f1 = foot_yaw(keys[1], b_)
            if math.dist(f0, f1) < sep_min: continue
            for c_ in range(-lim, lim+1, 5):
                f2 = foot_yaw(keys[2], c_)
                if math.dist(f1, f2) < sep_min or math.dist(f0, f2) < sep_min: continue
                mg = margin([f0, f1, f2])
                if best is None or mg > best[0]: best = (mg, a, b_, c_)
    crawl[lift] = {"legs": keys, "yaw_deg": list(best[1:]), "margin_mm": best[0]}

# ---- 8. rolling phase study: rigid body resting on 4 support functions
n_h = len(fine); step = 360.0/n_h
def h_at(deg_q): return fine[int(round((deg_q % 360)/step)) % n_h]
def rest(hs, pts):
    # minimise plane height at origin subject to plane >= h_i at each foot
    best = None
    idx = range(4)
    for c in itertools.combinations(idx, 3):
        M = [[1.0, pts[i][0], pts[i][1]] for i in c]; rhs = [hs[i] for i in c]
        det = (M[0][0]*(M[1][1]*M[2][2]-M[1][2]*M[2][1])
               -M[0][1]*(M[1][0]*M[2][2]-M[1][2]*M[2][0])
               +M[0][2]*(M[1][0]*M[2][1]-M[1][1]*M[2][0]))
        if abs(det) < 1e-9: continue
        def solve(col):
            N = [row[:] for row in M]
            for r in range(3): N[r][col] = rhs[r]
            return (N[0][0]*(N[1][1]*N[2][2]-N[1][2]*N[2][1])
                    -N[0][1]*(N[1][0]*N[2][2]-N[1][2]*N[2][0])
                    +N[0][2]*(N[1][0]*N[2][1]-N[1][1]*N[2][0]))/det
        z0, a, bb = solve(0), solve(1), solve(2)
        ok = all(z0+a*pts[i][0]+bb*pts[i][1] >= hs[i]-1e-7 for i in idx)
        if ok and (best is None or z0 < best[0]-1e-9):
            n_contact = sum(1 for i in idx if abs(z0+a*pts[i][0]+bb*pts[i][1]-hs[i]) < 1e-6)
            best = (z0, a, bb, n_contact)
    return best
pts4 = [F["FL"], F["FR"], F["RL"], F["RR"]]
def phase_study(offsets, name):
    z0s, pitch, roll, nc = [], [], [], []
    for k in range(0, 720, 2):
        q = k/2.0
        hs = [h_at(q+o) for o in offsets]
        z0, a, bb, n = rest(hs, pts4)
        z0s.append(z0); pitch.append(deg(math.atan(a))); roll.append(deg(math.atan(bb))); nc.append(n)
    return {"name": name, "offsets_deg": offsets,
            "heave_mm": max(z0s)-min(z0s),
            "pitch_abs_max_deg": max(abs(x) for x in pitch),
            "roll_abs_max_deg": max(abs(x) for x in roll),
            "contacts_min": min(nc), "contacts_max": max(nc)}
# order of pts4: FL, FR, RL, RR
phases = [phase_study([0,0,0,0], "all in phase"),
          phase_study([0,0,180,180], "front pair / rear pair 180"),
          phase_study([0,180,0,180], "left pair / right pair 180"),
          phase_study([0,180,180,0], "diagonal pairs 180"),
          phase_study([0,90,180,270], "90 deg spacing")]

# ---- 9. stair hook torque, steering torque
tau_stair = W["3pt"]*g["R_tread_mm"]/1000
w210_stall = w210["stall_Nm"]
trail = leg["stage1_axis_x_mm"]-leg["steer_axis_x_mm"]+arm0
tau_steer_loaded = 1.0*W["3pt"]*trail/1000
tau_steer_swing = 1.0*0.15*W["3pt"]*trail/1000

# ---- 10. regressions
assert abs(prof_c["heave_mm"]-prof_f["heave_mm"]) < val["profile_convergence_mm"]
assert abs(prof_f["heave_mm"]-33.24774921724) < 0.1
assert abs(tip_chord-136.97132152696) < 0.1
assert abs(A*math.sin(q1_0)+B*math.cos(q1_0)+leg["stage1_axis_z_mm"]-axle_z) < 1e-9
assert abs(L-195.307179) < 1e-4 and abs(deg(phi)-13.770009) < 1e-4
assert abs(deg(beta0)+50.406090) < 1e-4 and abs(arm0-124.477485) < 1e-4
assert abs(m4-T2) < 1e-9
assert all(abs(v) < 1e-6 for v in tri.values())
assert min(s["front_rear_gap_mm"] for s in postures) > val["moving_leg_clearance_mm"]
assert min(v["margin_mm"] for v in crawl.values()) >= val["static_margin_3pt_target_mm"]
assert abs(phases[3]["heave_mm"]) < 1e-6 and phases[3]["contacts_min"] >= 3

out = {
 "document_sha256": hashlib.sha256(doc.read_bytes()).hexdigest(),
 "scope": "D0 mathematical regression for the 4-leg platform; not fabrication acceptance",
 "derived": {"L_link_mm": L, "phi_off_deg": deg(phi), "beta_reference_deg": deg(beta0),
             "q1_reference_deg": deg(q1_0), "q2_reference_deg": deg(q2_0), "arm_mm": arm0,
             "ground_z_mm": ground, "axle_z_mm": axle_z,
             "frame_y_mm": 2*T2+body["frame_end_allowance_mm"],
             "wheelbase_mm": 2*(leg["stage1_axis_x_mm"]+arm0), "track_mm": 2*T2},
 "profile": {"coarse": prof_c, "fine": prof_f, "tip_chord_mm": tip_chord,
             "arc_only_distance_mm": roll_only,
             "distance_per_rev_mm": dist_rev,
             "tip_pivot_share_pct": 100*tip_chord/dist_rev,
             "lobe_roll_mm": dist_rev-roll_only-tip_chord},
 "loads_N": W, "torque_factor": kf,
 "postures": postures, "strides": strides,
 "roll_speed_max_m_s": roll_speed_max,
 "sector_section": {"I_mm4": I_sec, "Z_mm3": Z_sec, "moment_arm_mm": Lm,
                    "cantilever_mm": Ld, "sigma_5W_MPa": sigma5, "SF_5W": SF5,
                    "deflection_3W_mm": defl3},
 "support": {"feet_mm": F, "margin_4pt_mm": m4, "margin_3pt_mm": tri,
             "com_height_mm": h_com, "tipover_roll_deg": tip_roll, "tipover_pitch_deg": tip_pitch,
             "body_roll_for_80mm_deg": roll_for_margin(80.0),
             "same_side_yaw_limit_deg": same_side_yaw_limit,
             "crawl_with_yaw": crawl},
 "rolling_phase": phases,
 "stair_hook_torque_Nm": tau_stair, "stair_hook_pct_W210": 100*tau_stair/w210_stall,
 "steer": {"trail_mm": trail, "tau_loaded_Nm": tau_steer_loaded, "tau_swing_Nm": tau_steer_swing,
           "MX28_stall_Nm": p["actuator_catalog"]["MX-28AT"]["stall_Nm"]},
 "regression_status": "PASS"}
print(json.dumps(out, ensure_ascii=False, indent=1))
```
<!-- marc-reference-python:end -->

기하 파라미터를 바꾼 파생 후보에서는 기본값의 회귀 시험과 새 후보 평가를 분리한다. 기본값
assertion을 몰래 삭제하거나, 입력과 기대값을 함께 바꿔 PASS를 만들지 않는다.

**이 블록의 실행 결과로 rev.3에서 확정된 오류 하나가 다시 확인된다.** 접지호만 센 길이
당시 형상(접지호 225°)의 `2*pi*R_tread*(225/360) = 481.06 mm`가 문서 26/28/29와 ICRA 투고본에
"회전당 전진거리"로 실려 있었다. 그 형상의 실제 값은 752.81 mm였다. **개구각 75°로 바꾼 현재
형상**의 값은 회전당 **739.54 mm**이며, 접지호 416.92 mm + 로브 굴림 185.65 mm + 팁 피벗 현
136.97 mm(전체의 18.52%)로 나뉜다. **481 mm는 회전당 이동거리가 아니라 접지호의
호 길이였다.** 이 값을 쓴 모든 문서를 §19.3 목록에 따라 정정한다.
## 17. 필수 입력과 미해결 사항

### 17.1 입력 레지스트리

모든 입력은 `value, unit, source, revision, method, measured_at, uncertainty, status`를 갖는다. 도면 치수는 도면 리비전과 기준면, 실측은 장비·사진·측정 방향을 포함한다. 자료 확보 시 실제 파일을 source_manifest에 연결한다.

| ID | 필요한 입력 | 확보 방법과 구체적 완료 조건 | 막히는 작업 / 계속할 작업 |
|---|---|---|---|
| I01 | 실제 모터 ID·모델·펌웨어·영점·부호·모드 | 기존 하드웨어 매핑 읽기 → 보유품 기록 대조 → 승인된 캘리브레이션 작업의 관절별 방향 기록. 12개 행 완성 | 실물 제어·G02 하드웨어 / D0 FK 가능 |
| I02 | 혼·포크·베어링·스터브 인터페이스 | 제조사 STEP/PDF와 실제 부품 단면 확보. 중심/주변 체결, 잔여 벽, 빠짐 방지, 공구 경로가 유일하게 정의됨 | D1 허브/포크·G06 / 무공 D0 가능 |
| I03 | 실제 타이어 셀·벌크 밀도·고정 방식 | v2 제작 파일/슬라이서와 보유품 측정. 셀 반복 방향·피치·벽·외피·끼움/고정 치수 명시 | D1 TPU 질량·접촉 / 외형 프로파일 가능 |
| I04 | 프린터·재료·출력 방향·공차·강도·크리프 | 동일 출력 조건의 치수/강도/변형 시험. 설계 하중 방향별 값과 허용치 기록 | G06 실물 판정 / 예비 구조식 가능 |
| I05 | 센서·Jetson·U2D2 도면·질량·광학 변환·타이밍 | 제조사 원본/보유품 측정, 홀·포트·플러그와 optical 변환, 스테레오 캘리브레이션/시간차 기록 | 실제 패키징·G09 / 보수적 포락 가능 |
| I06 | 배터리/벅/퓨즈/커넥터/회로와 보호 조건 | 정확한 SKU 데이터시트, §8.2 정격표, 셀별 컷오프·전압 과도·역전력·e-stop 시험 | G08·PCB 제작 / 토폴로지·공간 예산 가능 |
| I07 | 모터 운전 한계·접촉 판별·동작 주기 | 공급 전압별 토크–속도 자료, 실제 전류 제한·온도·정지 유지 시험, 접촉 추정 실패 처리 | G04 운전/최적 park / 요구 토크 산출 가능 |
| I08 | 케이블·커넥터·배선/교체 경로 | 실제 케이블 SKU, 플러그 포락·길이·최소 곡률·고정점과 12축 경로 | G07 배선 제작 / 배선 공간 표시 가능 |
| I09 | 시스템 성공 조건과 실제 환경 | 다음 표의 미정 요구와 환경을 확보해 버전 고정 | 최종 성능 판정 / D0 기하 진단 가능 |

### 17.2 시스템 요구의 명시적 빈칸

| 항목 | 현재 값/상태 | 입력 형태 |
|---|---|---|
| 계단 높이 | 200mm 후보 목표 | 실제 높이와 허용 오차 mm |
| 계단 | 미정 | 디딤판 깊이, 코 반경/돌출, 폭, 단수, 상/하행, 마찰 |
| 탑재하중 | 미정 | 기본 전장 외 추가 kg와 CoM 범위 |
| 평지 속도 | 미정 | 목표 순변위 속도 m/s와 지형 |
| 운전 시간 | 미정 | 연속 보행/정지 유지 시간, 주위 온도 |
| 보행 안정성 | 정적 마진 80mm 후보 | 동적 전도/최대 roll-pitch/진동 허용치 |
| 센서 | 미정 | 검출 거리, 높이 오차, 지연, 이동 속도, 차폐 허용 시간 |
| 반복 성공 | 미정 | trial 수, 성공률, 실패/재시도 정의 |
| 제작 | 미정 | 출력판 크기, 분할 여부, 공차, 조립·교체 시간 |

목표/측정이 빠진 항목은 추가 추론으로 수치를 채우지 않는다. 필요한 입력을 표로 묶어 후속 작업에서 확보한다. 독립적으로 가능한 모델·계산을 끝낸 뒤 해당 입력 때문에 어떤 판정이 남았는지 보고한다.

## 18. 검토 지적의 반영과 인수인계

### 18.1 rev.2 검토 F01–F18 대응

| 검토 ID | rev.3 반영 위치 | 처리 |
|---|---|---|
| F01 정지 접지점 | §2, §6 | 실제 지지점 함수와 관절 모멘트 사용, park null |
| F02 하중/모터 | §3.3, §6.2–6.3 | 반력 평형, 자중, 토크–속도/열 한계, 중복 효율 제거 |
| F03 조향 | §7, §14.2 | 축 중심 이동 포함, 독립 조향·연속 경로 검사 |
| F04 로브 형상 | §2.1–2.2, §3.1 | 반경별 내곽, 양의 두께, 명시적 다각형 |
| F05 허브 | §4 | 잘못된 관통홀 삭제, 실제 인터페이스 도면 의존 |
| F06 구조 하중 | §3.4, §5.2 | 동일 하중·최종 공극 형상 비교, 무공 기준 |
| F07 전원 | §8.2 | 정격표·전류 제한·역전력·차단 검증 |
| F08 좌표/부호 | §11 | 좌우 오른손 좌표, q1/q2 영점, firmware sign 분리 |
| F09 실측 표현 | §1.2 | CAD 추정/스케치/실물 증거 구분 |
| F10 강도 | §3.4, §5.3 | 하중 경로·FEA·출력 이방성·체결·크리프 |
| F11 센서 | §8.3 | 비동기 영상/IMU, 광학 중심, 깊이 오차 조건 |
| F12 질량 | §8.4, §12 | 합계 정정, 부품 집계, 공극 중복 방지 |
| F13 안정성 | §7.3 | 실제 접점·CoM 범위 전체의 부호 있는 마진 |
| F14 성능 의미 | §2.4, §6.4 | 호 길이/회전 이동/속도/계단 성능 분리 |
| F15 제작/배치 | §4, §9, §17 | 실제 포트·인출·공차·출력 조건 입력 |
| F16 관성/이관 | §12 | 단위·기준점·텐서·축 검증, 별도 MARC 자산 |
| F17 실행성 | §10, §13–§16 | 파라미터 계약, 존재/예정 도구 구분, 실패 처리 |
| F18 독립 검증 | §15, §17 | 단계별 관문, 증거 필수, 미확정 목표 명시 |

### 18.2 다음 에이전트의 최종 보고 형식

`handoff.md`에는 다음 순서로 기록한다.

1. 실행 ID, 문서/CAD/코드 리비전, D0/D1/RELEASE 중 실제 상태.
2. 변경한 파일과 보존한 기존 자산, 생성한 Fusion document ID.
3. G00–G10 각각의 상태·측정값·허용치·증거 경로.
4. 실패 자세·부품·하중, 아직 측정되지 않은 I번호와 필드.
5. 그대로 실행할 다음 B단계와 명령. 그 파일이 실제 존재하는지 확인 후 적는다.
6. 새 후보가 필요하면 변경 파라미터·이유·재검사 관문을 제시한다.

‘코드 실행 성공’, ‘CAD 생성 성공’, ‘기구학 통과’, ‘실물 제작 가능’, ‘목표 성능 달성’을 서로 다른 상태로 보고한다. 문서에는 완료되지 않은 해석/측정을 완료형으로 쓰지 않는다.

## 19. 개정 이력과 주요 수치 변경

| rev | 날짜 | 변경 |
|---|---|---|
| 1 | 2026-09-09 | 최초 알루미늄/개단면 후보. 현재 설계의 원천 아님 |
| 2 | 2026-09-09 | PLA/TPU, 폐단면, 립/리브, 양단 지지, 신규 전원·센서 후보 도입. 정량 결론에 오류가 확인됨 |
| 3 | 2026-09-09 | 18개 검토 항목 반영. D0/D1/RELEASE 분리, 형상·축·접지·하중 재정의, 파라미터 JSON/기준 계산/관문/입력·실패 계약 추가 |
| **4** | **2026-09-09** | **6족 → 4족 전환. SCONE → MARC 개명(계열 전체 소급). 좌표계 +x 전방으로 재정의. 자세 모드(스파이더↔개) 정식화, 굴림 위상 배치 도입, yaw 재배치 정적 크롤 확립, G11 신설. 원본 코드·기존 CAD·하드웨어 설정은 변경하지 않음** |
| **4a** | **2026-09-09** | **D0 CAD 검수 반영.** 실제 모터 12개(MX-28AT×4 / XM430-W350-T×4 / XM430-W210-T×4) 형상 도입, 클레비스 절삭 규칙 확정, 요크 포락 미달 지적, 실측 CoM·전도각·정적 마진으로 §7.3 갱신, 토크 계수 0.75의 의미를 §6.2/§6.3에서 일치시킴 |

이번 개정 직전의 [rev.3 보존본](/Users/hayward_kim/Developer/SCONE/tmp/v3review/rev4-edit-20260909/30-scone-v3-design-plan.rev3.md)을
남겼다. 원문 해시는 `e8acb6aa97263f5a29e61ce416133aec96e0c6218980283d7bba60615ca48ae5`다.
[rev.2 보존본](/Users/hayward_kim/Developer/SCONE/tmp/v3review/rev3-edit-20260909/30-scone-v3-design-plan.rev2.md)도
그대로 있다. 보존본과 검토 보고서는 과거 근거이고, 새 구현에는 현재 rev.4를 사용한다.

### 19.1 rev.3 → rev.4 주요 수치

| 항목 | rev.3 (6족) | rev.4 (4족) |
|---|---:|---:|
| 다리 / 관절 / 모터 | 6 / 18 / 18 | **4 / 12 / 12** |
| 총질량 후보 | 4.945 kg (D0 추정) | **3.615 kg** (상한 후보 3.90) |
| 다리당 정적 반력 `N_ref` | 14.94 N (3점) | **11.82 N** (3점) |
| 좌표계 | +x 우현 / +y 전방 | **+x 전방 / +y 좌현** |
| 몸체 외곽 | x±65, y±212.5 | **x±65, y±175** |
| 다리 배치 | 종방향 3열, 피치 175 mm | **네 모서리, 트랙 320 / 축거 465 mm** |
| 종 리브 | 없음 | **x=±50 신설 (앞뒤 조향축 직결)** |
| 중앙 요크 연장 25 mm | 있음 | **삭제** |
| 기준 자세 설계토크 (3점) | 98% stall | **72%** |
| 개 자세 설계토크 (3점) | 53% | **39%** |
| 계단 걸기 토크 | 1.98 N·m | **1.45 N·m (W210의 48.3%)** |
| 다리 하나 들었을 때 마진 | 86.6 mm | 0 mm (yaw 고정) → **104.4 mm** (yaw 재배치, 실측 CoM) |
| 4점 정적 마진 | — | **160.0 mm** |
| 전도각 (롤/피치) | — | **36.00° / 48.11°** (D0 실측 CoM) |
| 굴림 상하동요 | 미검토 | **0.00 mm** (대각짝 180°) |
| 굴림 몸 기울기 | 0.12° / 0.16° | 2.29° / 3.32° |
| 부채꼴 면외 Z / SF | 720 mm³ / 5.85 (근사 표기) | **725.6 mm³ / 5.86** (단면식 명시) |
| 스테레오 광학 중심 | (0,205,40), 높이 313 | **(70,0,70), 높이 343** |
| 스테레오 지면 교점 | 219.2–3577.6 mm | **240.2–3920.6 mm** |
| 라이다 스캔 평면 | z=90.3 | **z=96.3** |
| yaw 탐색 범위 | −110..+90° | **±60°** (같은 쪽 벌림 한계 ±64°) |
| 질량 상한 후보 | 4.75 kg | **3.90 kg** |
| 하중 케이스 | LC01..LC07 | **LC08(트롯 착지) 추가** |
| 관문 | G00..G10 | **G11(자세 모드 한계) 추가** |

바뀌지 않은 것: R_tread 122.5 / 로브 45° / 팁 112.5, 링크 등가 길이 195.307179 mm,
`phi_off` 13.770009°, 기준 차고 255 mm, 재료(PLA + TPU 95A), 폐단면 링크, 양단 지지 클레비스,
D0/D1/RELEASE 단계, I01–I09 입력 레지스트리.

### 19.2 rev.4에서 철회한 rev.3 결론

§0.4에 있다. 요약하면 ① "부채꼴 4개로는 최소 2점 접지" ② "접지호를 270°로 키워야 함"
③ "조향 없이는 전방 굴림 불가" ④ "role-split 보행 필수" ⑤ "4족은 다리를 들면 정적 마진이 0이라
정적 크롤 불가" 다섯 가지다. ①②③④는 rev.3까지의 잘못된 전제에서 나왔고, ⑤는 rev.4 작성 중
yaw 재배치 해를 찾아 뒤집혔다.

### 19.4 rev.4a — D0 CAD 검수에서 바뀐 것

GPT가 만든 D0 모델(`artifacts/marc/20260909_125258_rev4-D0`)을 독립 검수하고 같은 Fusion 문서를
고친 결과다. 검수 산출물은 `artifacts/marc/<타임스탬프>_rev4-D0-review/`에 있다.

| # | 지적 | 원인 | 조치 |
|---|---|---|---|
| R1 | 모터 12개가 모델에 없음 | 도면 확보 전이라 생성 보류 | 저장소의 실물 메시(`src/assets/meshes/BODY_ACTUATOR.stl`, `LEG_ACTUATOR.stl`, 수밀 확인)를 §11.1 축 좌표에 배치 |
| R2 | 링크가 부채꼴을 관통 (다리당 3.50 cm³) | §4.1의 포크 도달 22 mm가 R_tread 122.5 mm보다 짧음 | 클레비스 절삭 규칙을 §4.1에 확정하고 D0에 적용. 교차 0 |
| R3 | 요크 포락이 모터보다 작음 | 실물 없이 정한 포락 | §5.1에 부족량과 최소 요구치 명기 |
| R4 | 루트 질량 9.49 kg (기본 강철) | 포락 바디에 재료 미배정 | 부품별 실효밀도 재료 배정. 루트 질량이 명시 집계와 일치 |
| R5 | 관절 한계각 없음 | G11 미구현 | yaw ±60°, q1 −29.594°..+25.406°(Fusion 기준) 설정 |
| R6 | `com_z_candidate_mm = 12` | 추정값 | 실측 −65.076으로 교체, 전도각·마진 재계산 |
| R7 | §6.2와 §6.3의 효율 0.75 모순 | 같은 이름을 다른 뜻으로 사용 | `drive_efficiency` → `external_loss_factor`로 개명하고 두 절에 근거 명시 |

**검수에서 되돌린 것.** 모터를 부모 링크에 강체 조인트로 묶었더니 Fusion이 조립을 다시 풀면서
모터 12개를 모두 대각선 반대 모서리로 옮겼다. 조인트를 지우고 좌표만 다시 지정했다.
모터가 관절을 따라 움직이게 만드는 것은 B06/D1 과제로 남긴다. 운동학적 부모는 메타데이터로만
기록되어 있다.

**바뀌지 않은 것.** 부채꼴·타이어 프로파일, 링크 등가 길이, 기준 자세, 프레임·데크·탑재물 배치,
파라미터 48개의 값(위 두 개 제외), 관문 체계.
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

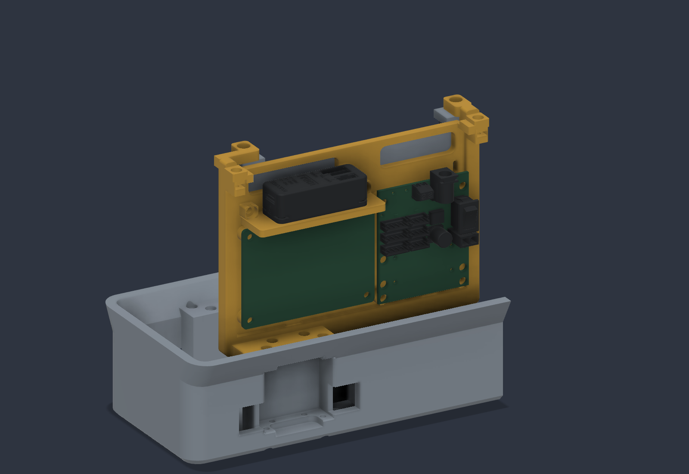
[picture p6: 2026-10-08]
artifacts/electronics/20260930_jetson_carrier/DELIVERY/preview.png

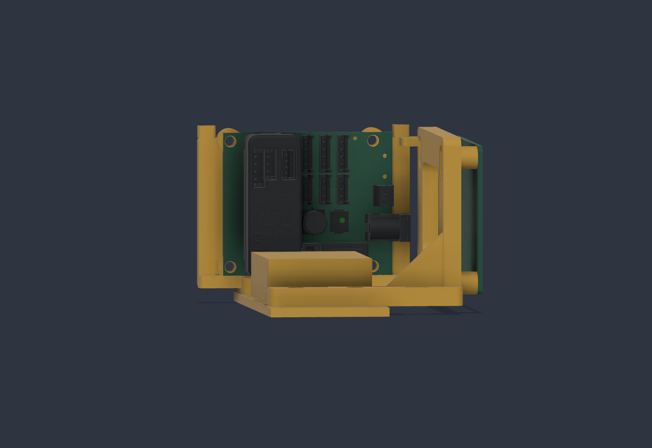
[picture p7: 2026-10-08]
artifacts/electronics/20260930_vertical_carrier/carrier_preview.png

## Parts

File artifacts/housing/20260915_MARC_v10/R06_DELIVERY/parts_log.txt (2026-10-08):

R01 INVALID
R02 solids 5 mm3 -0.2
S01 INVALID
S02 INVALID
P04 solids 1 mm3 22438.61
R06 PARTS BUILT
[32;1m
*******************************************************************
******        Statistics on Transfer (Write)                 ******

*******************************************************************
******        Transfer Mode = 0  I.E.  As Is       ******
[0m
[32;1m******        Transferring Shape, ShapeType = 0                      ******
[0m
[32;1m** WorkSession : Sending all data
[0m
[32;1m Step File Name : /Users/hayward_kim/Developer/SCONE/artifacts/housing/20260915_MARC_v10/R06_DELIVERY/R02.step(1527 ents)  Write  Done
[0m
[32;1m
*******************************************************************
******        Statistics on Transfer (Write)                 ******

*******************************************************************
******        Transfer Mode = 0  I.E.  As Is       ******
[0m
[32;1m******        Transferring Shape, ShapeType = 0                      ******
[0m
[32;1m** WorkSession : Sending all data
[0m
[32;1m Step File Name : /Users/hayward_kim/Developer/SCONE/artifacts/housing/20260915_MARC_v10/R06_DELIVERY/P04.step(8059 ents)  Write  Done
[0m

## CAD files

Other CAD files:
artifacts/housing/20260915_MARC_v10/R09_DELIVERY/rejected/R01_incomplete_boolean.step
artifacts/housing/20260930_c1_l1/delivery/C1_L1_assembly_coordinates.step
artifacts/housing/20260915_MARC_v10/R07_DELIVERY/assembly_clip.step
artifacts/housing/20260915_MARC_v10/R08_DELIVERY/assembly_clip.step
artifacts/housing/20260915_MARC_v10/R03_DELIVERY/printed_parts_assembly.step
artifacts/housing/20260915_MARC_v10/R08_DELIVERY/PRINT_PACKAGE/printed_parts_assembly.step
artifacts/housing/20260915_MARC_v10/R09_DELIVERY/PRINT_PACKAGE/printed_parts_assembly.step
artifacts/electronics/20260930_jetson_carrier/DELIVERY/E10_Jetson_electronics_carrier.step
artifacts/electronics/20260930_jetson_carrier/DELIVERY/STL/P4_1.stl
artifacts/electronics/20260930_vertical_carrier/ROBOTIS_U2D2PHB.step
artifacts/housing/20260915_MARC_v10/R03_DELIVERY/R01_PLA_mm.stl
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

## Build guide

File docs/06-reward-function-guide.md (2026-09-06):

# 보상함수 수정 가이드

> 범위: 이 문서의 본문은 기존 70차원 `walk_learn` 정책을 설명한다. 새 82차원
> `walk_v2`의 현재 보상식, 실제 35.4M-step 항별 기여와 문제점은
> [`21-walk-v2-ppo-training-analysis.md`](21-walk-v2-ppo-training-analysis.md)를
> 기준으로 한다. 76차원 `walk_v3`의 보상은 구조가 다르다 — 단측 속도 보상,
> 높이 항 없음, 자세 비용·종료가 하드 제약 —
> [`22-walk-v3-residual-design.md`](22-walk-v3-residual-design.md) §3을 본다.
> 세 환경의 숫자와 checkpoint를 섞어 쓰면 안 된다.

## 1. 기준 파일과 변경 지점

기존 정책 보상함수의 최종 기준은 [`src/rl/walk_learn.py`](../src/rl/walk_learn.py)의 다음 세 부분이다.

1. `RewardConfig`: sigma, weight, soft/hard limit
2. `SconeWalkEnv._reward()`: raw 측정값, 정규화, aggregate, 종료 조건
3. `RewardTermsCallback`: TensorBoard에 기록하는 항목

[`08-rl-development-log.md`](08-rl-development-log.md)의 숫자는 개발 기록이며 현재 기본값과 일부 다르다. 실험 설정을 기록할 때는 `RewardConfig` 전체와 Git commit/working-tree diff를 함께 저장한다.

## 2. 현재 보상 수식

기호:

- `Δt = control_dt = physics_timestep × frame_skip`, 기본 `0.02 s`
- `v = (vx, vy)`, `c = (command_vx, command_vy)`
- `ω = (roll_rate, pitch_rate, yaw_rate)`, `cω = command_yaw_rate`
- `g`는 body frame projected gravity
- `a_t`는 현재 18차원 residual action
- 모든 `w_*`와 `σ_*`는 `RewardConfig`의 대응 필드

### 명령 추종과 방향

```text
linear_tracking = exp(-||v - c||² / σ_linear²)
yaw_tracking    = exp(-(ωz - cω)² / σ_yaw²)
heading_tracking = exp(-heading_error² / σ_heading²)
upright          = exp(-||gxy||² / σ_gravity²)
```

각 tracking 값은 최적일 때 1, 오차가 커질수록 0에 가까워진다.

### 자세와 진동

```text
height_drop = max(0, reference_height - root_height)
height_penalty = (height_drop / σ_height)²

oscillation_penalty =
    (vz / σ_vertical)²
  + (ωroll / σ_roll_pitch)²
  + (ωpitch / σ_roll_pitch)²
```

높이는 one-sided다. 기준보다 높아지는 것은 벌하지 않고, 낮아지는 collapse만 벌한다.

### action과 idle

```text
action_rate_penalty      = mean((a_t - a_(t-1))²)
action_magnitude_penalty = mean(a_t²)

activity = clip(max(abs(command / command_scale)), 0, 1)
idle_fraction = clip(1 - activity / idle_activity_threshold, 0, 1)

idle_velocity_tracking = exp(
    -||v||² / σ_idle_linear²
    -ωz² / σ_idle_yaw²
)
idle_action_penalty = idle_fraction * action_magnitude_penalty
```

`idle_fraction`은 완전 neutral에서 1이고 threshold에 도달하면 0이다. 일반 tracking sigma보다 훨씬 작은 idle sigma가 미세한 정지 진동을 구분한다.

### 미끄러짐, 전류, 관절, 충돌

접촉점 미끄러짐:

```text
point_velocity = J_contact * qvel
tangential = point_velocity - normal * dot(point_velocity, normal)
excess = max(0, ||tangential|| - slip_deadzone)
slip_penalty = mean((excess / σ_slip)²) over valid tire contacts
```

normal force가 `contact_force_threshold` 미만인 접촉과 swing leg는 계산하지 않는다.

전류:

```text
current = (voltage - K * joint_velocity) / R
stall_current = stall_torque / K
current_penalty = mean((current / stall_current)²)
```

관절:

```text
joint_offset = abs(joint_position - default_radians)
excess = max(0, joint_offset - soft_joint_offset)
joint_limit_penalty = mean((excess / radians(15))²)
```

`forbidden_collision`은 1 N 이상인 ground 접촉 중 tire가 아닌 robot body가 닿으면 참이다. `collision_penalty`는 그 boolean의 0/1 값이다.

## 3. aggregate와 최종 합계

```text
velocity_term = Δt * (
    w_velocity * linear_tracking
  + w_idle_velocity * idle_fraction * idle_velocity_tracking
)

direction_term = Δt * (
    w_yaw * yaw_tracking
  + w_heading * heading_tracking
)

stability_term = Δt * (
    w_upright * upright
  - w_height * height_penalty
  - w_oscillation * oscillation_penalty
  - w_slip * slip_penalty
  - w_joint_limit * joint_limit_penalty
  - w_collision * collision_penalty
)

damping_term = -Δt * (
    w_action_rate * action_rate_penalty
  + w_action_magnitude * action_magnitude_penalty
  + w_idle_action * idle_action_penalty
  + w_current * current_penalty
)

total = velocity_term + direction_term + stability_term + damping_term
```

종료 조건이면 마지막에 `termination_penalty=5.0`을 한 번 뺀다. termination penalty만 `Δt`를 곱하지 않는다.

중요: `info["reward_terms"]`에는 세부 항과 aggregate가 함께 있다. 다음처럼 전부 합하면 중복 계산된다.

```python
# 잘못된 검증: velocity/yaw/upright 등의 세부 항과 aggregate가 겹친다.
sum(info["reward_terms"].values())
```

정확한 비종료 합계 검증은 네 aggregate만 사용한다.

```python
terms = info["reward_terms"]
expected = terms["velocity"] + terms["direction"] + terms["stability"] + terms["damping"]
```

종료 시에는 `terms["termination"]`도 한 번 더한다.

## 4. 현재 기본값

### sigma와 한계

| 필드 | 기본값 | 작게 만들면 | 크게 만들면 |
|---|---:|---|---|
| `linear_velocity_sigma` | 0.25 m/s | 정확한 xy 추종만 높은 점수 | 큰 속도 오차도 비슷한 점수 |
| `yaw_velocity_sigma` | 0.15 rad/s | yaw-rate 정밀 추종 | yaw 오차에 관대 |
| `heading_error_sigma` | 0.60 rad | heading drift에 민감 | heading drift에 관대 |
| `projected_gravity_sigma` | 0.25 | 작은 기울기도 구분 | 기울어져도 upright 보존 |
| `height_sigma` | 0.05 m | 작은 하강도 큰 penalty | collapse guard가 느슨 |
| `vertical_velocity_sigma` | 0.30 m/s | bounce에 민감 | 수직 진동에 관대 |
| `roll_pitch_rate_sigma` | 0.80 rad/s | 흔들림에 민감 | 회전 진동에 관대 |
| `slip_deadzone` | 0.02 m/s | 접촉 노이즈까지 penalty | 작은 실제 slip도 무시 |
| `slip_sigma` | 0.20 m/s | deadzone 이후 penalty 급증 | slip에 관대 |
| `soft_joint_offset` | 60° | 더 일찍 관절 penalty | 큰 자세 변화 허용 |
| `hard_joint_offset` | 90° | 더 일찍 종료 | 위험 각도까지 episode 유지 |

### weight

| 보상 | weight | penalty | weight |
|---|---:|---|---:|
| linear velocity | 2.0 | height | 0.05 |
| yaw rate | 1.0 | oscillation | 0.1 |
| heading | 0.75 | action rate | 0.02 |
| upright | 0.5 | action magnitude | 0.25 |
| idle velocity | 1.0 | idle action | 0.5 |
|  |  | current | 0.02 |
|  |  | slip | 0.1 |
|  |  | joint limit | 0.2 |
|  |  | collision | 1.0 |
|  |  | termination | 5.0 |

## 5. 가장 안전한 수정 절차

### 1단계: 증상을 측정한다

먼저 “잘 못 걷는다”를 구체적인 관측값으로 바꾼다.

| 증상 | 먼저 볼 로그 |
|---|---|
| 명령보다 느림 | `state/vx`, `reward/velocity`, action magnitude, current |
| 회전 명령 부정확 | `state/yaw_rate`, heading error, `reward/yaw`, `reward/heading` |
| 정지 시 떨림 | idle velocity/action, action rate, z/roll/pitch 진동 |
| 자세가 낮아짐 | height, height_drop, upright, current |
| 발이 끌림 | stance contact 수, slip, reference phase |
| 관절이 끝으로 감 | joint limit, residual distribution, termination |
| 자주 넘어짐 | fallen/collision/hard limit 원인별 빈도 |

### 2단계: sigma와 weight 중 하나만 바꾼다

- sigma는 “오차의 의미 있는 크기”를 정한다.
- weight는 정규화된 목표끼리의 우선순위를 정한다.
- tracking이 너무 넓어 좋고 나쁜 상태를 구분하지 못하면 sigma를 먼저 조정한다.
- scale은 적절하지만 다른 목표에 비해 중요도가 낮으면 weight를 조정한다.
- 한 실험에서 한 항 또는 한 가족만 바꾼다. 보통 25–50% 범위 변화부터 시작한다.

### 3단계: 코드 기본값 대신 설정 객체로 먼저 검증한다

환경을 직접 만들 때는 기본값을 영구 수정하지 않고 실험 설정을 주입할 수 있다.

```python
from src.rl.walk_learn import RewardConfig, SconeWalkEnv

reward_config = RewardConfig(
    velocity_weight=2.5,
    action_magnitude_weight=0.30,
    slip_weight=0.15,
)
env = SconeWalkEnv(reward_config=reward_config, curriculum="full")
```

현재 CLI의 `_build_env()`는 `reward_config` argument를 노출하지 않는다. 정식 실험 방법은 다음 중 하나다.

- 실험 branch에서 `RewardConfig` 기본값을 바꾸고 diff를 보존한다.
- CLI에 reward preset/설정 파일 argument를 추가하고 `_build_env()`까지 전달한다.

재현성이 필요한 여러 실험은 두 번째 방식이 낫다. 문자열로 임의 Python 표현을 실행하는 방식은 사용하지 않는다.

### 4단계: 고정 명령과 동일 seed로 비교한다

- zero action baseline으로 reference gait 자체를 확인한다.
- forward `(0.25,0,0)`, reverse, yaw, idle을 각각 분리한다.
- 같은 terrain/seed/standing pose로 before/after를 비교한다.
- 최소 3개 이상의 학습 seed와 여러 episode 평균을 사용한다.
- 평균 reward만 보지 말고 성공률, 속도 오차, fall 원인, current, slip을 같이 본다.

### 5단계: 짧은 검증 후 새 run을 시작한다

```bash
python -m src.rl.walk_learn check --steps 500 --curriculum easy
python -m src.rl.walk_learn check --steps 500 --curriculum full --random-actions
python -m src.rl.walk_learn train \
  --timesteps 100000 \
  --curriculum easy \
  --num-envs 4 \
  --output runs/reward_trial_name \
  --tensorboard-log runs/tensorboard
```

terrain 같은 global option은 subcommand 앞에 둔다.

```bash
python -m src.rl.walk_learn --terrain uneven --terrain-seed 7 check --steps 500
```

## 6. 항목별 조정 예시

### 속도를 더 잘 따라가게 하고 싶다

1. `linear_velocity_sigma`가 실제 달성 가능한 오차보다 너무 작은지 확인한다.
2. 너무 작으면 tracking이 거의 항상 0이 되어 gradient 신호가 약하므로 먼저 약간 늘린다.
3. tracking 값이 상태를 잘 구분하는데 우선순위만 낮으면 `velocity_weight`를 올린다.
4. policy가 큰 residual로 속도만 얻는다면 action/current/slip도 함께 확인하되 한 번에 모두 바꾸지 않는다.

### 정지 시 떨림을 줄이고 싶다

1. `idle_fraction`이 실제 neutral command에서 1인지 확인한다.
2. drift가 남으면 `idle_linear_velocity_sigma`/`idle_yaw_velocity_sigma`가 구분 가능한 범위인지 확인한다.
3. residual bias가 크면 `idle_action_weight`를 올린다.
4. active gait까지 둔해지면 일반 `action_magnitude_weight` 대신 idle 항만 조정한다.
5. 재생 시에는 reward와 별도로 `NeutralResidualGate`가 활성인지 확인한다.

### 넘어짐을 줄이고 싶다

- 자세가 계속 기울면 `upright_weight` 또는 gravity sigma를 검토한다.
- 높이만 낮아지면 one-sided `height_weight`를 검토한다.
- 매우 빠른 흔들림이면 `oscillation_weight`를 검토한다.
- 너무 빠른 termination은 policy가 회복을 배우지 못하게 할 수 있으므로 fall 경계와 penalty를 동시에 과도하게 강화하지 않는다.
- actuator가 포화되어 자세를 못 버티는 문제는 reward만으로 고치지 말고 motor spec, PID, 질량, 초기 자세를 먼저 확인한다.

### 미끄러짐을 줄이고 싶다

1. contact normal/point velocity가 맞는지 시각·수치로 확인한다.
2. `slip_deadzone`은 접촉 solver 노이즈보다 약간 크게 둔다.
3. `slip_sigma`로 “나쁜 slip 속도”의 규모를 정한다.
4. 마지막에 `slip_weight`를 올린다.
5. rolling drive를 학습할 계획이라면 현재 접선속도 penalty가 의도한 wheel rolling까지 벌할 수 있으므로 contact model을 분리한다.

### 에너지 사용을 줄이고 싶다

`current_weight`를 올리기 전에 motor `K/R/stall_torque`, XML dcmotor nominal 값과 Python `DCMotorSpec`이 일치하는지 확인한다. 값이 틀리면 reward가 물리 비용이 아니라 모델링 오차를 최적화한다.

## 7. 새 보상 항을 추가하는 방법

예를 들어 foot clearance 항을 추가한다면 다음 순서를 따른다.

1. `RewardConfig`에 `clearance_sigma`, `clearance_weight`를 추가한다.
2. `__post_init__()`에서 sigma가 양수이고 weight가 finite/non-negative인지 검증한다.
3. `_reward()`에서 물리량을 측정하고 먼저 무차원 raw penalty로 정규화한다.
4. `stability_term` 또는 `damping_term` 중 한 aggregate에 정확히 한 번 포함한다.
5. `raw_terms["clearance"]`에 weighted 값을 넣어 TensorBoard에 기록한다.
6. `total`에는 aggregate만 사용하며 세부 clearance를 또 더하지 않는다.
7. 단위 테스트를 만든다: 최적/나쁜 상태의 부호, weight=0, aggregate 합계, termination과 독립성.
8. zero action baseline과 random action smoke test를 실행한다.

권장 형태:

```python
clearance_penalty = normalized_clearance_error
stability_term -= reward.clearance_weight * clearance_penalty * self.control_dt
raw_terms["clearance"] = (
    -reward.clearance_weight * clearance_penalty * self.control_dt
)
```

## 8. 반드시 유지할 불변 조건

- 모든 sigma는 `> 0`이어야 한다.
- reward와 observation은 finite여야 한다.
- 보상/penalty weight는 의미상 음수가 되지 않게 한다.
- penalty term은 총합에 음수, tracking term은 양수로 들어간다.
- step reward는 termination을 제외하고 `control_dt`로 시간 정규화한다.
- action과 관측 shape를 바꾸면 기존 PPO checkpoint와 학습 resume가 호환되지 않는다.
- 관절 제한은 기준 자세 offset가 아니라 최종적으로 실제 기계 범위를 사용해야 한다.
- collision/slip 항은 정확한 geom 이름과 contact force threshold에 의존한다.
- reward 계산에서 physical controller를 열거나 명령하지 않는다.

현재 `RewardConfig.__post_init__()`는 idle threshold와 idle sigma만 검증한다. 다른 sigma를 0으로 바꾸면 division-by-zero가 발생할 수 있으므로, 보상 수정 작업에서는 모든 sigma/weight에 대한 validation을 함께 추가하는 것이 안전하다.

## 9. checkpoint 재사용 판단

| 변경 | 기존 checkpoint 재생 | 기존 checkpoint에서 학습 재개 | 권장 |
|---|---|---|---|
| weight/sigma만 변경 | 가능 | 기술적으로 가능 | 비교 실험은 새 run 권장 |
| termination 기준 변경 | 가능 | 가능하지만 데이터 분포 급변 | 새 run 또는 명시적 fine-tune |
| observation 값/순서/차원 변경 | shape가 같아도 의미 불일치 위험 | 권장하지 않음 | 새 run |
| 68→70차원 변경 | legacy adapter로 재생만 | 불가 | 새 run |
| action 차원/scale/관절 순서 변경 | 위험/불가 | 불가 | 새 run |
| standing pose/reference gait 변경 | 로드는 가능 | objective/동작 의미 변경 | 새 run 또는 별도 fine-tune 이름 |

on-policy PPO라도 과거 objective로 만들어진 policy/value state를 새 reward로 이어갈 수는 있다. 하지만 새 reward의 순수한 효과를 비교하는 실험이라면 동일 seed의 새 학습을 사용한다.

## 10. heading 적분 회귀 계약

`SconeWalkEnv.step()`은 아래 heading 적분을 policy step마다 정확히 한 번 수행한다.

```python
self._target_heading += self._command[2] * self.control_dt
```

heading/yaw weight나 step 순서를 바꿀 때는 이 적분이 중복되거나 빠지지 않도록 다음 계약을 유지한다.

- 일정 yaw command에서 N step 후 target heading이 `yaw_rate×control_dt×N`인지
- zero yaw에서 target heading이 변하지 않는지
- `±π` 경계를 지날 때 `_heading_error()`가 wrap되는지

## 11. 최소 회귀 테스트 목록

- 완벽한 속도/자세 상태에서 tracking 항이 최대인지
- linear/yaw error를 늘리면 각 tracking이 단조 감소하는지
- reference보다 높은 body는 height penalty 0인지
- reference 아래 body만 height penalty가 생기는지
- neutral에서 idle action penalty가 활성인지
- active command에서 idle fraction이 0인지
- action이 고정이면 action-rate penalty 0인지
- tire contact가 없으면 slip penalty 0/contact count 0인지
- forbidden body contact가 collision/termination을 만드는지
- soft joint limit 전에는 0, 이후 증가, hard limit 이후 종료인지
- `total = velocity+direction+stability+damping(+termination)`인지
- 모든 reward/diagnostic이 finite인지
- 70차원 관측과 18차원 action 계약이 유지되는지

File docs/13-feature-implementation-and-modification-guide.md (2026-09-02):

# SCONE 기능 구현 및 코드 수정 가이드

> **현재 gait 이름/route:** 연속 lower velocity 회전은 `roll-gait`/
> `RollGait`다. `scone-gait`는 checkpoint 필수 PPO/점접지 hybrid supervisor다.
> 계단은 `Walk → Drive → Climb` 준비 뒤 custom phase를 시작하고, 물리 Drive는
> stage-1 register를 read-back한다. 최신 수정점과 수식은
> [`14-roll-gait-and-hybrid-scone-gait.md`](14-roll-gait-and-hybrid-scone-gait.md)가
> 우선한다.

이 문서는 2026-09-01 현재 SCONE의 주요 기능이 **어떤 경로로 실행되고,
어느 코드에서 구현되며, 기능을 바꾸려면 무엇을 함께 수정하고 검증해야
하는지**를 한곳에 정리한 개발자용 안내서다. 세부 수식과 시행착오는 기존
주제별 문서에 남기고, 여기서는 실제 코드 수정의 출발점과 영향 범위를
중심으로 설명한다.

코드와 문서가 다를 때의 최종 기준은 다음 순서다.

1. `src/`와 루트 진입점의 현재 코드
2. `tests/`가 고정하는 동작
3. 이 문서와 주제별 문서
4. `archive/`의 구형 코드·논문·영상

---

## 1. 전체 구조와 수정 경계

### 1.1 공통 제어 흐름

실물과 시뮬레이션은 상위 API를 공유하지만 controller 구현은 분리돼 있다.

```text
SCONE.py / python -m src.simulation / python -m src.rl
                         │
                    src/cli.py
                         │
       ┌─────────────────┼──────────────────┐
       │                 │                  │
 Legacy Walk/Drive  model-based gait    PPO joystick
       │                 │                  │
       └───────────── SCONE facade ─────────┘
                         │
                ControllerProtocol
                  ┌──────┴──────┐
                  │             │
       hardware.Controller  MuJoCoController
                  │             │
             DYNAMIXEL       model.xml + terrain
```

핵심은 [`ControllerProtocol`](../src/hardware/interface.py)이다. 실제
[`Controller`](../src/hardware/controller.py)와 시뮬레이션
[`MuJoCoController`](../src/simulation/core/controller.py)가 같은 위치·속도·
torque·mode API를 구현하므로 [`SCONE`](../src/main.py)과 legacy locomotion은
backend를 몰라도 동작한다.

단, 다음 기능은 의도적으로 MuJoCo 전용이다.

- 연속 lower velocity 회전을 사용하는 비-RL `roll-gait`
- 정체 감지와 대각 삼각 후킹을 사용하는 `scone-stair`
- 자동 계단 `hardcoded/improved/compare` 데모
- MuJoCo body state와 contact를 관측하는 PPO 환경

이 기능을 실물로 옮기는 것은 controller 이름만 바꾸는 작업이 아니다. 실제
joint hard stop, TPU 마찰·변형, 전류·온도, 낙상 정지, 통신 지연을 측정한
안전 계층이 먼저 필요하다.

### 1.2 기능별 기준 파일

| 기능 | 실행 진입점 | 핵심 구현 | 주 회귀 테스트 |
|---|---|---|---|
| 통합 launcher와 조이스틱 | [`SCONE.py`](../SCONE.py), [`src/cli.py`](../src/cli.py) | `KeyboardJoystick`, `run_velocity_joystick_cli()`, `main()` | [`test_api.py`](../tests/test_api.py) |
| 공용 robot API | [`src/main.py`](../src/main.py) | `SCONE`, `RobotCommand`, `RobotStatus` | [`test_api.py`](../tests/test_api.py) |
| 하드웨어 탐색·통신 | [`src/hardware/`](../src/hardware) | `discover_hardware()`, `Controller`, actuator table | [`test_actuators.py`](../tests/test_actuators.py), [`test_api.py`](../tests/test_api.py) |
| Legacy Walk/Drive/Climb | [`src/locomotion/`](../src/locomotion) | `Walk`, `Drive`, `Climb`, `LegacyVelocityAdapter` | [`test_api.py`](../tests/test_api.py), [`test_simulation.py`](../tests/test_simulation.py) |
| FK/IK | [`src/kinematics/`](../src/kinematics) | `LegKinematics`, `RobotKinematics` | [`test_kinematics.py`](../tests/test_kinematics.py) |
| MuJoCo 모델·motor loop | [`src/simulation/core/`](../src/simulation/core) | `load_model()`, `MuJoCoController`, `DCMotorPID` | [`test_simulation.py`](../tests/test_simulation.py) |
| 절차형 지형 | [`src/simulation/terrain/`](../src/simulation/terrain) | `TerrainGenerator`, `STAIR_PRESETS`, `SLOPE_PRESETS` | [`test_terrain.py`](../tests/test_terrain.py) |
| `tripod-gait` | [`tripod_gait.py`](../src/locomotion/tripod_gait.py) | `TripodGait`, `GaitConfig` | [`test_tripod_gait.py`](../tests/test_tripod_gait.py), [`test_simulation.py`](../tests/test_simulation.py) |
| RL bounded `scone-gait` | [`scone_gait.py`](../src/locomotion/scone_gait.py) | `SconeGait`, `SconeGaitConfig` | [`test_scone_gait.py`](../tests/test_scone_gait.py), [`test_rl_reference_motion.py`](../tests/test_rl_reference_motion.py) |
| 연속 회전 `roll-gait` | [`scone_rolling_gait.py`](../src/simulation/core/scone_rolling_gait.py) | `RollGait` | [`test_scone_rolling_gait.py`](../tests/test_scone_rolling_gait.py) |
| PPO/점접지 hybrid `scone-gait` | [`joystick_control.py`](../src/rl/joystick_control.py) | `SconeHybridController` | [`test_rl_joystick.py`](../tests/test_rl_joystick.py) |
| 계단 후킹·자동 데모 | [`stair_climber.py`](../src/simulation/core/stair_climber.py), [`stair_demo.py`](../src/simulation/core/stair_demo.py) | `SconeStairClimber`, `HardcodedStairRoller` | [`test_stair_geometry.py`](../tests/test_stair_geometry.py), [`test_stair_climber.py`](../tests/test_stair_climber.py), [`test_stair_demo.py`](../tests/test_stair_demo.py) |
| RL 환경·reward·PPO | [`walk_learn.py`](../src/rl/walk_learn.py) | `SconeWalkEnv`, `RewardConfig`, `WalkConfig` | [`test_remote_watch.py`](../tests/test_remote_watch.py), [`test_rl_reference_motion.py`](../tests/test_rl_reference_motion.py) |
| RL 조종·호환성 | [`joystick_control.py`](../src/rl/joystick_control.py), [`policy_compat.py`](../src/rl/policy_compat.py) | `NeutralResidualGate`, `_RLModeRouter`, 68→70 replay adapter | [`test_rl_joystick.py`](../tests/test_rl_joystick.py), [`test_remote_watch.py`](../tests/test_remote_watch.py) |
| 원격 학습·checkpoint | [`inquiry.py`](../src/rl/inquiry.py), [`remote_watch.py`](../src/rl/remote_watch.py) | SSH job lifecycle, atomic mirror, ZIP 검사 | [`test_rl_inquiry.py`](../tests/test_rl_inquiry.py), [`test_remote_watch.py`](../tests/test_remote_watch.py) |

### 1.3 수정 전에 지켜야 할 세 원칙

첫째, `src/simulation/cli_bridge.py`, `controller.py`, `model.py`, `pid.py`,
`simulator_cli.py`는 과거 import를 살리는 호환 shim이다. 실제 구현은 대부분
`src/simulation/core/`에 있으므로 shim에 새 로직을 중복해서 넣지 않는다.

둘째, `non_rl`과 `NonRLWalk`은 이전 이름의 호환 경로다. 현재 정식 명칭은
`tripod-gait`이다. 새 UI·설정·문서에는 정식 이름을 쓰고, 저장된 job과 외부
코드 때문에 alias만 유지한다.

셋째, 학습 당시의 reference motion, standing pose, 관측 순서, action scale,
motor dynamics는 checkpoint 의미의 일부다. 이 중 하나를 바꾼 뒤 기존 PPO를
그대로 재개하면 같은 action 값이 다른 관절 목표를 뜻하게 된다.

---

## 2. 모터 ID, 단위와 방향

### 2.1 ID 배열

[`ActuatorIndex`](../src/hardware/actuator_index.py)가 모든 그룹의 기준이다.

| 관절 단계 | ID | 다리 `n`의 ID |
|---|---|---|
| 몸체/upper | 1–6 | `n` |
| 다리 1단/middle | 7–12 | `n + 6` |
| 말단 sector/lower | 13–18 | `n + 12` |

대각 tripod는 다음 두 그룹이다.

- `TRIPOD_A` / `*_DIAGONAL_RIGHT`: 다리 `(1, 4, 5)`
- `TRIPOD_B` / `*_DIAGONAL_LEFT`: 다리 `(2, 3, 6)`

여기서 LEFT/RIGHT는 물리적인 한쪽 면이 아니라 기존 코드의 tripod phase
이름이다. 그룹 이름만 보고 좌우 세 다리로 해석하면 gait가 꼬인다.

### 2.2 단위

| 값 | 단위/규약 |
|---|---|
| 조이스틱 `vx, vy` | m/s, body frame |
| 조이스틱 `yaw_rate` | rad/s, 양수는 좌회전 |
| locomotion motor target | degree |
| 실제 DYNAMIXEL position | `0..4095` raw/회전 |
| MuJoCo `qpos/qvel` | rad, rad/s |
| lower goal velocity | DYNAMIXEL velocity unit |
| 지형 치수 | metre |
| physics timestep | second |

조이스틱의 화면 `+x`는 오른쪽이지만 model body `+y`는 왼쪽이다. 변환은
[`JoystickState.to_velocity_command()`](../src/cli.py)에서
`vy = -x * max_vy`로 한 번만 수행한다. 방향을 바꿀 때 gait 내부와
controller의 부호를 동시에 뒤집지 말고, 다음 순서로 원인을 나눈다.

1. UI axis → body command
2. body command → foot/sector 목표
3. mirrored lower axis → raw velocity
4. contact reaction → 실제 body displacement

---

## 3. 통합 launcher와 키보드 조이스틱

### 3.1 구현 방식

[`src/cli.py`](../src/cli.py)의 `main()`은 장치를 비파괴 탐색한 뒤 다음 메뉴를
연다.

- 시뮬레이션 자동 데모
- 시뮬레이션 조종
- 실제 하드웨어 조종
- 하드웨어 재탐색
- 강화학습 관리

[`src/cli_i18n.py`](../src/cli_i18n.py)는 `Language`, `localize()`,
`terrain_label()`을 제공한다. `SCONE.py`는 실제 command-line argument를
`src.cli.main()`으로 전달하며 기본 `english`, `--language korea` 한국어를
지원한다. 언어는 root launcher에서 simulation picker, joystick HUD,
PPO reference/stance picker, RL 관리 메뉴까지 명시적으로 전달한다. 내부 enum
value와 command 문자열은 번역하지 않으므로 언어를 바꿔도 실행 의미가 같다.

[`src/cli_ui.py`](../src/cli_ui.py)는 모든 대화형 화면의 공통 레이아웃을
담당한다. 바깥 폭은 74 terminal column, 내부 구분선은 72개의 `-`로 고정한다.
`display_width()`가 한글 전각 문자를 2열로 계산하므로 영어와 한글 모두 오른쪽
경계가 같은 열에 놓인다. 긴 문구는 `wrap_display()`가 panel 내부에서 줄바꿈하며
redirect된 log에는 ANSI escape를 쓰지 않는다.

화면 갱신 규칙은 다음과 같다.

- root launcher, profile, terrain, controller, checkpoint, RL picker로 전환할 때
  `clear_terminal()`로 이전 화면을 지운 뒤 새 고정폭 header를 그린다.
- joystick은 50 Hz cursor-home 갱신으로 값과 stick 위치를 덮어쓰고, terminal
  잔상이 남지 않도록 1초마다 전체 `cls`(`ESC[2J`, `ESC[H`)를 추가 수행한다.
- 실제 하드웨어 discrete control은 매 키 입력 뒤 같은 panel을 다시 그리고 마지막
  명령 결과를 `[ STATUS ]`에 유지한다.
- launcher 오류나 종료 알림은 다음 화면의 `Notice` 행에 전달하여 `cls` 직후
  사라지지 않게 한다. RL 작업 결과는 Enter 확인 전에는 지우지 않는다.

시뮬레이션 세부 선택은
[`src/simulation/core/simulator_cli.py`](../src/simulation/core/simulator_cli.py),
실행 route는
[`src/simulation/core/cli_bridge.py`](../src/simulation/core/cli_bridge.py)가
담당한다. `SimulationControl`은 현재 `old`, `tripod-gait`, `scone-gait`,
`roll-gait`, `scone-stair`, `rl`을 제공한다. `scone-gait`와 `rl`은 checkpoint가
필수이고, `roll-gait`는 비-RL 연속 회전이다.

`KeyboardJoystick`은 terminal에 key-up event가 없다는 점을 timeout으로
처리한다. 키 입력은 0.35초 동안 axis를 유지하고 OS key repeat가 deadline을
갱신한다. `run_velocity_joystick_cli()`는 50 Hz로 다음 순서를 반복한다.

```python
state = joystick.state()
command = state.to_velocity_command(limits)
apply_command(command, dt)
```

`Space`와 종료 시에는 명시적으로 zero command를 보내므로 마지막 속도
명령이 남지 않는다.

### 3.2 조이스틱 기능 수정 방법

키를 추가하거나 바꾸려면:

1. `_JOYSTICK_KEY_BINDINGS` 또는 `_TERMINAL_KEY_SEQUENCES`를 수정한다.
2. `_normalize_key()`에 platform alias가 필요한지 확인한다.
3. `render_joystick_ui()`의 도움말과 표시를 같이 수정한다.
4. [`test_api.py`](../tests/test_api.py)의 axis, timeout, neutral 테스트를
   추가한다.

속도 한계를 바꾸려면 UI 배율을 하드코딩하지 말고 해당 controller의
`GaitConfig` 또는 `JoystickLimits`를 바꾼다. PPO 조종 한계는 학습 관측의
`OBSERVATION_COMMAND_SCALE`에서 오므로 일반 gait 한계와 따로 관리한다.

새 simulation control을 추가하려면:

1. `SimulationControl` enum에 정식 문자열을 추가한다.
2. `select_simulation_control()`에 사용자 label을 추가한다.
3. `cli_bridge.run()`의 worker 분기에 adapter를 연결한다.
4. 직접 CLI가 필요하면 `build_parser()` 선택지와 필수 argument 검사를
   추가한다.
5. 메뉴 dispatch는 `test_api.py`, simulation route는 `test_simulation.py`에
   테스트한다.

UI 문구나 언어를 추가하려면:

1. 새 내부 command value를 만들지 말고 기존 value와 표시 label을 분리한다.
2. 공용 영어/한국어 문구는 `localize(language, english, korean)`로 선택한다.
3. 새 picker/worker 함수에는 `language=Language.ENGLISH` 기본 인자를 두어 기존
   Python 호출을 깨지 않는다.
4. thread에서 그리는 joystick UI에는 언어를 인자로 전달한다. thread-local
   전역 상태에 의존하지 않는다.
5. `test_api.py`에서 영어 기본값, `korea` 선택, 같은 menu value, 한국어 HUD를
   함께 검사한다.

CLI 레이아웃을 수정하려면:

1. 개별 화면에서 임의 길이의 `-`나 box를 만들지 말고 `render_panel()`을 쓴다.
2. picker는 `show_picker_screen()`으로 화면 삭제, 제목, 조작 안내를 한 번에
   적용한다.
3. 의도적인 들여쓰기와 한글이 있어도 모든 행의 `display_width()`가 74인지
   `tests/test_cli_ui.py`에서 확인한다.
4. 동적 화면은 매 frame 전체 삭제하지 않는다. cursor-home 갱신을 기본으로 하고
   `_JoystickTerminal._full_clear_interval`에 따라 주기적으로 전체 삭제한다.
5. 비대화형 CI/log에는 ANSI 문자가 섞이지 않아야 하므로 `clear_terminal()`의
   TTY 판정을 우회하지 않는다.

---

## 4. 공용 `SCONE` API와 수명주기

### 4.1 구현 방식

[`src/main.py`](../src/main.py)의 `SCONE`은 construction 시 port를 열거나
움직이지 않는다. controller를 주입한 뒤 `initialize()`해야 명령을 받는다.

초기화 순서는 다음과 같다.

1. 전체 torque off
2. lower 13–18을 position mode로 복귀
3. XM acceleration 20 설정
4. torque on
5. safety speed에서 middle 시작 자세
6. upper profile 자세
7. lower profile 자세
8. middle profile 자세
9. walking speed로 복귀하고 `Walk` mode 생성

`forward/backward/left/right`는 현재 `Mode` 객체로 위임된다. `change_mode()`는
`Walk → Drive → Climb → Walk`의 객체 교체를 수행한다. `shutdown()`은 middle을
종료 자세로 옮긴 뒤 torque를 끄고, `close()`는 controller까지 닫는다.

### 4.2 API 수정 방법

새 자세 profile을 추가하려면
[`src/locomotion/profile.py`](../src/locomotion/profile.py)에 immutable
`MotionProfile`을 만들고 `PROFILES`에 등록한다. 다음을 함께 확인한다.

- upper tuple이 정확히 6개인가
- middle/lower 초기 자세가 실제 기구 한계 안인가
- walking/driving/climbing speed 의미가 기존 model과 같은가
- `initialize()`의 이동 순서에서 충돌하지 않는가
- MuJoCo standing seed 또는 RL standing pose와 혼동되지 않는가

새 public command를 추가하려면 `RobotCommand`, `SCONE.execute()`의 dispatch,
현재 mode의 구현과 `SCONE.py` export를 함께 수정한다. mode에 없는 동작은
`UnsupportedCommandError`로 실패해야 하며 조용히 무시하지 않는다.

실제 로봇 수명주기를 바꿀 때는 fake controller 테스트만으로 충분하지 않다.
지지대 위에서 torque-off, mode switch, 목표 위치 순서와 비상 정지를 별도로
확인한다.

---

## 5. 실제 DYNAMIXEL 하드웨어

### 5.1 구현 방식

하드웨어 계층은 네 부분으로 나뉜다.

- [`actuator_index.py`](../src/hardware/actuator_index.py): ID와 관절 그룹
- [`actuator_control_table.py`](../src/hardware/actuator_control_table.py):
  model별 protocol, register address와 byte 크기
- [`discovery.py`](../src/hardware/discovery.py): 후보 port를 열고 ID 1/7/13을
  ping하는 비파괴 탐색
- [`controller.py`](../src/hardware/controller.py): 실제 read/write, model별
  `GroupSyncWrite`, torque/mode/position/velocity API

upper 1–6은 MX-28AT Protocol 1.0, middle/lower 7–18은 XM430 Protocol 2.0이다.
`Controller._sync_write()`는 요청을 `(protocol, register)`로 묶으므로 서로
다른 register width를 한 packet으로 섞지 않는다.

`set_mode()`는 지원 model에서 torque를 끄고 operating mode를 쓴 뒤 다시
켠다. upper MX에는 operating-mode register가 없으므로 무시한다. lower만
position/velocity mode를 전환하는 것이 현재 locomotion의 전제다.

### 5.2 하드웨어 수정 방법

motor model 또는 register를 바꾸려면:

1. datasheet에서 model number, protocol, address, byte size를 확인한다.
2. `ActuatorModel`과 `ControlTable`을 추가/수정한다.
3. [`actuator.py`](../src/hardware/actuator.py)의 `model_for_id()` 매핑을
   갱신한다.
4. read/write가 signed 값인지 확인한다. 특히 goal velocity의 음수 encoding을
   sync write의 bit mask와 함께 검증한다.
5. `test_actuators.py`에서 ID별 model/register 선택을 고정한다.
6. 실제 bus에서는 한 ID씩 torque off 상태로 검증한 뒤 group write로 넓힌다.

serial port 기본값을 바꾸는 것보다 `SCONE_DEVICE` 환경 변수를 우선 사용한다.
탐색을 수정할 때도 torque, mode, position write를 넣지 않는다.

---

## 6. Legacy `Walk / Drive / Climb`

### 6.1 구현 방식

Legacy 계열은 검증된 blocking motor sequence를 보존한다.

- [`Walk`](../src/locomotion/walk.py): 대각 tripod를 hold/release하며 전후진,
  upper/middle 목표로 좌우 회전
- [`Drive`](../src/locomotion/drive.py): lower를 velocity mode로 바꿔 C자
  말단을 주행 바퀴처럼 회전
- [`Climb`](../src/locomotion/climb.py): 한 tripod를 지지하고 반대 tripod의
  middle/lower를 교대하는 기존 등반 sequence
- [`LegacyVelocityAdapter`](../src/locomotion/legacy_velocity.py): 연속
  `VelocityCommand`를 가장 가까운 discrete 명령으로 바꾸고 background
  thread에서 최신 명령만 실행

이 경로는 model-based `tripod-gait`와 다르다. `Walk`는 정해진 position과
sleep 순서를 실행하고, `TripodGait`는 50 Hz 발 궤적과 IK를 생성한다.

### 6.2 Legacy 동작 수정 방법

자세나 순서를 바꾸려면:

1. `walk.py`, `drive.py`, `climb.py` 중 실제 mode를 먼저 특정한다.
2. 반복되는 ID는 숫자 tuple을 새로 만들지 말고 `Actuator.Index` 그룹을
   사용한다.
3. profile 속도는 `MotionProfile`에서, 한 동작의 임시 speed만 mode 내부에서
   바꾼다.
4. mode 종료 시 lower operating mode와 zero velocity가 다음 mode의 전제와
   맞는지 확인한다.
5. blocking sleep을 바꾸면 실물뿐 아니라 MuJoCo worker와 자동 benchmark의
   준비 시간도 달라짐을 기록한다.

`LegacyVelocityAdapter`의 방향 임계값을 바꿀 때는 translation과 yaw가 동시에
들어온 경우 어떤 discrete 동작을 우선할지 테스트해야 한다.

---

## 7. FK/IK와 말단 접촉점

### 7.1 구현 방식

[`LegKinematics`](../src/kinematics/leg.py)는 MJCF 이름으로 한 다리의 세
joint와 `TIRE_n` body를 찾는다. 별도 링크 길이 상수를 복제하지 않고 MuJoCo
forward kinematics와 Jacobian을 사용한다.

inverse kinematics는 position-only damped least squares다.

```text
Δq = Jᵀ (J Jᵀ + λ²I)⁻¹ e
```

큰 step은 `max_step`으로 제한하고 backtracking으로 residual이 줄어드는
candidate만 받는다. 세 관절로 말단 위치 3개 축은 풀지만 tire orientation을
독립적으로 지정하지는 않는다.

[`RobotKinematics`](../src/kinematics/robot.py)는 여섯 `LegKinematics`가 하나의
MuJoCo model/data를 공유하게 하고, `(6, 3)` 또는 actuator 순서 `(18,)`를
상호 변환한다.

`TripodGait`는 `TIRE_n` body origin 대신 nominal pose에서 tire mesh의 가장
낮은 0.1 mm patch 중심을 support point로 추론한다. 한쪽 mesh vertex만
선택해서 생기는 불필요한 lateral moment를 피하기 위해서다.

### 7.2 FK/IK 수정 방법

MJCF joint/body 이름을 바꾸면 `LegKinematics.__init__()`의 이름 규칙과
`MuJoCoController._find_actuator()`의 `A01_..A18_` 규칙을 함께 수정한다.

IK tolerance/damping을 조정할 때는:

- `test_kinematics.py`의 FK→IK round trip
- `test_tripod_gait.py`의 여섯 다리 convergence
- gait의 `ik_backoff_scale`과 failed leg
- 실제 frame의 연속성

을 같이 본다. convergence 비율만 높이기 위해 tolerance를 느슨하게 하면
발 접촉점 오차와 slip을 숨길 수 있다. MJCF에 실제 mechanical joint range가
아직 없으므로 simulation IK 성공을 실물 안전 범위로 해석하지 않는다.

---

## 8. MuJoCo 모델, controller와 physics loop

### 8.1 모델 load

[`load_model()`](../src/simulation/core/model.py)은 원본
[`model.xml`](../src/assets/model.xml)을 runtime에 XML로 수정한다.

1. fixed/floating base 선택에 따라 root freejoint를 삽입하거나 제거
2. contact mesh의 최저점으로 simulation floor 높이 계산
3. 선택 terrain primitive geom 삽입
4. STL asset bytes와 함께 MuJoCo model compile

원본 MJCF에 매 terrain을 직접 복사하지 않으므로 robot asset과 실험 course를
분리할 수 있다.

### 8.2 simulated motor

[`MuJoCoController`](../src/simulation/core/controller.py)는 actuator 이름
`A01_..A18_`로 joint, qpos, dof address를 찾고 18개의
[`DCMotorPID`](../src/simulation/core/pid.py)를 만든다. position mode에서는
profile velocity/acceleration으로 setpoint를 만든 뒤 PID가 voltage를
출력하고, velocity mode에서는 goal velocity를 추종한다. 최종 torque는
motor spec, voltage, back-EMF와 saturation의 영향을 받는다.

초기 qpos는 raw CAD rest가 아니라 standing pose로 seed하고, floating root를
들어 올려 최저 contact mesh가 floor 위 2 mm에 놓이게 한다. 이 과정은
초기 `initialize()` torque-off에서 차체가 접힌 자세로 무너지는 transient를
줄인다.

비-RL MuJoCo `tripod-gait`는 `configure_model_gait_controller()`가 profile
limit를 `0`으로 풀고 middle position stiffness를 2배로 올린다. 연속 회전형
`scone-gait`는 별도의 `SconeRollingGaitConfig`에서 160/50 profile과 stiffness
2배를 적용한다. 두 opt-in 튜닝 모두 PPO replay에는 적용하지 않는다.

### 8.3 simulation 수정 방법

motor 성능을 바꾸려면 `pid.py`의 model spec과 `controller.py`의 outer-loop
gain을 구분한다.

- torque/speed/전기 사양 변경: `DCMotorSpec`
- position 응답 변경: `default_gains_for_motor_id()` 또는 opt-in stiffness
- DYNAMIXEL profile 의미 변경: `set_speed()`, `set_acceleration()`
- mirrored lower 방향 변경: `arc_wheel_velocities()`

이 값은 학습 동역학이다. 바꾼 뒤 기존 checkpoint 성능이 달라지는 것은
호환성 오류가 아니라 환경 자체가 달라진 결과일 수 있다. 새 정책을 학습할
경우 run 이름과 설정에 변경점을 남긴다.

viewer loop는 controller update 후 `mujoco.mj_step()`을 실행한다. 자동 계단
데모는 60 Hz render와 2 ms physics를 분리하고 timeout도 simulation time을
사용한다. GUI timeout을 wall clock으로 되돌리면 느린 rendering 환경에서
실험이 조기 종료된다.

---

## 9. 절차형 terrain

### 9.1 구현 방식

[`TerrainType`](../src/simulation/terrain/types.py)은 `flat`, `uneven`,
`stairs-1..3`, `slope-1..3`, `mixed`를 정의한다.
[`TerrainGenerator`](../src/simulation/terrain/generator.py)는 box/ramp primitive를
현재 cursor 뒤에 이어 붙이고 geom 이름, 시작/끝 위치, 최대 높이를 반환한다.
`uneven`과 `mixed`의 random 요소는 `terrain_seed`로 재현된다.

현재 계단 preset은 다음과 같다.

| preset | 각 riser | tread |
|---|---:|---|
| `stairs-1` | 100 mm × 3 | 300/270/240 mm |
| `stairs-2` | 150 mm × 3 | 270/230/200 mm |
| `stairs-3` | 200 mm × 3 | 350/350/350 mm |

200 mm preset의 tread 350 mm는 한 tripod가 tread를 지지하는 동안 다른
tripod가 simulated hook assist를 수행할 공간을 확보하기 위한 현재 검증값이다.

### 9.2 terrain 수정 방법

단높이·폭·tread만 바꿀 때는
[`presets.py`](../src/simulation/terrain/presets.py)의 `StairProfile`을 수정한다.
새 지형 종류를 추가할 때는:

1. `TerrainType`과 label 추가
2. 필요한 profile dataclass/preset 추가
3. `TerrainGenerator.build()` route 추가
4. mixed course 포함 여부 결정
5. simulator argparse와 interactive picker 노출 확인
6. `test_terrain.py`에서 XML compile, 치수, seed 재현성 검증

계단 치수를 바꾸면 `SconeStairClimber.maximum_rise`의 direct-roll 판정,
자동 데모의 `_top_thresholds()`, benchmark 성공 threshold까지 다시
검증한다. 단순히 terrain이 compile되는 것만으로 climbing 성공을 보장하지
않는다.

---

## 10. `tripod-gait`

### 10.1 구현 방식

[`TripodGait`](../src/locomotion/tripod_gait.py)은 Phoenix 계열의 고전 교대
삼각보를 SCONE의 3D IK와 결합한다.

각 다리의 nominal contact 위치 `r_i = (x_i, y_i)`에서 body twist가 요구하는
발 속도는 다음과 같다.

```text
v_foot,i = [vx - yaw_rate*y_i,
            vy + yaw_rate*x_i]

stroke_i = v_foot,i * duty_factor / cycle_frequency
```

요청 stroke가 전후/측면 타원 workspace를 넘으면 방향은 유지한 채 경계까지
축소한다. stance에서는 발을 body 명령 반대 방향으로 이동하고, swing에서는
minimum-jerk 보간과 `16s²(1-s)²` lift로 다음 위치에 되돌린다. 여섯 foot
target을 IK로 풀어 18개 motor degree를 만든다.

현재 비-RL MuJoCo 조종은
[`TRIPOD_GAIT_SIMULATION_CONFIG`](../src/simulation/core/cli_bridge.py)를 사용한다.

- 50 Hz control
- 1.0 Hz cycle
- duty 0.5
- 25 mm lift
- 90 mm 전후, 70 mm 측면 workspace
- 최대 4회 0.8배 IK backoff
- simulation profile velocity/acceleration 제한 해제

이 값은 simulation-only measured tuning이다. `GaitConfig`의 library default와
RL reference 설정은 의도적으로 다르다.

### 10.2 `tripod-gait` 수정 방법

튜닝은 다음 순서로 한 변수군씩 진행한다.

1. 좌표/부호: 작은 `vx`에서 여섯 foot target과 root displacement 확인
2. nominal stance/support point: idle IK가 현재 자세를 유지하는지 확인
3. cadence와 duty
4. `max_stride`/`max_lateral_stride`와 clipping 비율
5. step height
6. IK tolerance/backoff
7. simulated motor profile/stiffness

`max_vx`만 올려도 stroke workspace가 이미 포화라면 실제 보폭은 늘지 않는다.
다음 식으로 먼저 clipping을 예측한다.

```text
requested_stride = |v| * duty_factor / cycle_frequency
```

수정 후에는 최소한 `test_tripod_gait.py`와 `test_simulation.py`를 실행하고,
8초 flat run에서 전진·측면 drift·yaw·역방향 누적·root Z·IK failure를 함께
측정한다. 평균 전진만 보면 앞뒤 움직임이 상쇄되는 문제를 놓칠 수 있다.

실물 적용 시 `reset_from_controller()`로 현재 joint 위치를 nominal stance로
잡는 것이 권장된다. 현재 simulation route는 초기 중력 sag에서 불안정한 IK
branch를 잡지 않도록 검증된 profile pose를 유지한다.

---

## 11. `roll-gait`, bounded reference, multi-turn hybrid `scone-gait`

서로 내부 planner를 공유하지만 실행 목적이 다르므로 수정 전에 구분한다.

| 경로 | 클래스 | lower 제어 | 용도 |
|---|---|---|---|
| bounded reference/position controller | [`SconeGait`](../src/locomotion/scone_gait.py) 기본값 | point hold + bounded position sweep | RL 학습 reference 호환 |
| 비-RL MuJoCo `roll-gait` | [`RollGait`](../src/simulation/core/scone_rolling_gait.py) | continuous velocity + basic motion rate | 실제로 여러 바퀴 회전하는 실험 gait |
| checkpoint 필수 `scone-gait` | [`SconeHybridController`](../src/rl/joystick_control.py) | phase-gated multi-turn position | 저속/yaw PPO와 고속 보행+회전 전환 |

### 11.1 RL bounded `SconeGait`

`SconeGait`은 `TripodGait`의 upper/middle/lower position frame에 sector
tangent와 steering solution을 더한다. stance 앞 55%에서는 추가 sector
phase를 고정하고, late stance에서만 회전한 뒤 swing에서 되감는다. 기본값은
0.65 Hz, 35/25 mm stride, 25 mm lift, ±30° sector sweep이다. output이 항상
18개 bounded position이므로
다음 residual 합성이 가능하다.

```text
target = reference_motor_degrees
       + residual_scale_degrees * policy_action
```

이 클래스를 연속 회전으로 바꾸면 기존 position residual의 의미가 사라진다.
RL에서 unbounded roll을 학습하려면 action/observation/controller 설계를
별도 버전으로 만들고 새 checkpoint를 학습해야 한다.

### 11.2 비-RL 연속 회전 `RollGait`

`RollGait`은 내부 `SconeGait` planner로 몸통·middle 기본 보행을
계산하면서 lower를 velocity mode로 운용한다.

1. ID 1–12에는 planner position 전송
2. lower rolling target을 contact tangent와 command로 계산
3. planner lower의 nominal 대비 offset을 미분
4. 미분값을 velocity unit으로 바꾸고 limit/low-pass
5. continuous roll과 0.35배 basic lower motion을 합성

```text
v_lower = lowpass(v_roll, 0.10 s)
        + 0.35 * lowpass(d(Δq_basic)/dt, 0.04 s)
```

현재 주요 값은 roll velocity 175, support ratio 0.80, tripod B phase 60°,
planner 0.8 Hz/duty 0.58/55 mm stride/20 mm lift다. 시작할 때 `prepare()`가
C자 개구부 phase를 나눠 position으로 정렬하고, `activate()`가 lower를
velocity mode로 바꾼다.

### 11.3 PPO/hybrid `scone-gait`

`SconeHybridController`는 평면 속도 `sqrt(vx²+vy²)`가 0.10 m/s 이하면 PPO만,
0.18 m/s 이상이면 1.2 Hz/90 mm/25 mm의 `SconeGait` multi-turn reference만 쓴다.
중간은 smoothstep으로 reference를 섞고 같은 비율만큼 PPO residual을 줄인다.
따라서 제자리 yaw는 항상 PPO이고, full hybrid에서 학습하지 않은 residual이
새 reference와 싸우지 않는다.

고속 config는 `continuous_rotation=True`다. stance 앞 55%는 말단 추가 회전을
멈춰 한 점으로 지지하고, late stance와 swing 앞 70%에서 같은 방향 회전을
누적하며 착지 전 30%에서 감속한다. 각속도는
`(180/π)||[vx-ωy,vy+ωx]||/0.1225`이고 360°/s로 제한한다. 최종 lower 목표는
`q_IK + 누적 회전각`이라 2단 기본 보행을 버리지 않는다. checkpoint lower와
multi-turn lower는 가장 가까운 360° branch에서 보간한다. 상세 식과 15.4M
실측은 14번 문서를 따른다.

### 11.4 gait 수정 방법

화면에서 “회전만 한다”면 먼저 다음 telemetry를 확인한다.

- upper nominal 대비 최대 명령각
- middle nominal 대비 최대 명령각
- planned lower offset과 basic velocity
- lower 실제 회전수

full-body 연속 회전 크기를 바꾸려면 `RollGaitConfig`의
`cycle_frequency`, `duty_factor`, `step_height`, `max_stride`를 조정한다.
말단 추진을 바꾸려면 `roll_velocity`, `support_velocity_ratio`,
`basic_lower_motion_blend`를 조정한다. 두 군을 동시에 크게 올리면 같은 추진을
중복 요구해 yaw와 height drop이 커질 수 있다.

checkpoint `scone-gait`의 누적회전은 `SconeHybridControlConfig`의
`point_support_ratio`, `swing_roll_hold_ratio`, `effective_roll_radius`,
`max_roll_rate_degrees`로 조정한다. bounded 학습 reference의
`sector_sweep_degrees`와 혼동하지 않는다.

phase를 바꿀 때는 한 번의 전진 거리뿐 아니라:

- 여섯 opening이 동시에 바닥을 향하는지
- lateral excursion과 최종 drift
- 최대 yaw
- root Z 최저값과 upright
- lower 회전수
- IK failure와 합성식 오차

를 6–20초 동안 본다. `test_scone_rolling_gait.py`는 full-body movement,
연속 회전, phase, drift/height 회귀를 고정한다.

---

## 12. 부채꼴 후킹과 계단 이동

### 12.1 기하 계산

[`stair_geometry.py`](../src/locomotion/stair_geometry.py)는 현재 SCONEv2
arc-wheel 외반경, 내반경, opening angle을 묶고 다음 계산을 제공한다.

- riser가 radial band에 들어오는지
- clearance를 포함한 보수적 direct-roll 한계
- sharp edge offset `sqrt(2Rh-h²)`
- quasi-static pivot torque와 horizontal push
- 필요한 마찰계수
- support polygon margin

현재 외반경은 `R = 122.5 mm`다. `rise + clearance <= R` 같은 식은 후킹
가능성을 검토하는 기하 분석에는 남아 있지만, 현재 계단 controller의 모드
전환 조건은 아니다. 현재 구현은 모든 높이에서 먼저 공통 위상을 획득한다.

전체 공식과 가정은
[`11-scone-stair-climbing.md`](11-scone-stair-climbing.md)를 기준으로 한다.

### 12.2 synchronized-phase `scone-stair`

[`SconeStairClimber`](../src/simulation/core/stair_climber.py)은 주행 Drive와
별개의 계단 모션이다. 정지 `IDLE`에서 시작하고 다음 상태를 거친다.

```text
IDLE
  └─ prepare ─> SYNCHRONIZING
                    └─ six targets settled ─> IDLE
                           └─ command ─> CLIMBING
                                            └─ command 0 ─> IDLE/phase hold
```

하나의 wrap하지 않는 기하 위상 `θ`를 사용한다. 현재 MJCF에서 홀수/짝수
lower joint 축이 반대이므로 실제 C-frame 각도를 같게 하려면 목표는 다음과
같다.

```text
odd lower target  = θ
even lower target = 360° - θ
θ[k+1] = θ[k] - v_phase × (0.229 × 6 deg/s) × dt
```

lower 여섯 개는 `EXTENDED_POSITION` mode를 유지한다. 따라서 계단 모서리에
걸린 모터가 지연되어도 동일한 공통 목표로 돌아오며, 서로 다른 tripod lower
속도나 Drive velocity는 보내지 않는다. lower 위상 전에 진행 방향 앞쪽 1단
IDs `(7,9,11)`을 높이별로 `180/184/195°`에 둔다. 현재 측정 기반 lower
선택값은 100 mm `60°/250`, 150 mm `60°/200`, 200 mm `90°/200`이다. 앞은
시작 위상, 뒤는 DYNAMIXEL velocity 수치 단위의 phase rate다.

`prepare_scone_stair_pose()`는 Legacy Walk에서 네 번 회전해 course `+Y`에
side-on으로 놓고 Walk→Drive와 Drive→Climb 준비를 차례대로 완료한다. 그 뒤
custom brace/phase가 Legacy Climb 제어를 대체한다. 이 준비 sequence는 terrain
방향과 결합돼 있으므로 course axis를 바꾸면 함께 수정해야 한다.

### 12.3 자동 데모와 benchmark

[`stair_demo.py`](../src/simulation/core/stair_demo.py)는 조종 입력 없이 다음을
실행한다.

- `hardcoded`: 옛 코드처럼 앞쪽 1단 270° 수직 자세를 만든 뒤 lower 60°를
  한 번 획득하고 velocity 200 open-loop
- `improved`: 높이별 앞 1단 partial brace와 공통 lower 위상 목표를 계속
  추종하는 `SconeStairClimber`
- `compare`: 두 viewer를 순서대로 실행

[`stair_benchmark.py`](../src/simulation/stair_benchmark.py)는 GUI 없이 기존
H0–H4 기록과 새 `synchronized-open-loop` 기준선을 같은 준비 조건에서
JSONL로 출력한다.

계단 controller를 수정할 때는:

1. odd/even physical phase 변환과 config validation 수정
2. phase acquisition/state transition 단위 테스트
3. headless 동일 조건 benchmark
4. 자동 데모 result/timeout 테스트
5. macOS `mjpython` viewer에서 실제 route 확인
6. 시도·실패·채택 이유를 계단 문서에 기록

현재 결정론적 headless에서 hardcoded는 100/150 mm를 `3.804/4.268 s`에
통과하지만 upright가 `0.608/0.438`까지 내려가고 200 mm에는 실패한다.
improved는 `2.594/4.194/5.996 s`, upright `0.912/0.752/0.760`으로 세 높이를
통과한다. 이는 현재 model과 마찰 설정의 simulation 결과이지 실물 성능
보증이 아니다.

---

## 13. Residual RL 환경

### 13.1 environment step

[`SconeWalkEnv`](../src/rl/walk_learn.py)는 command-conditioned residual PPO
환경이다.

```text
command update
  → target heading/phase update
  → reference motion 생성
  → reference + 18D residual
  → position target 전송
  → 10 × (controller update + 2 ms physics)
  → observation/reward/termination
```

`WalkConfig.physics_timestep = 0.002`, `frame_skip = 10`이므로 physics는
500 Hz, policy는 50 Hz다.

### 13.2 action

action은 raw current가 아니라 `[-1, 1]` 범위의 18개 position residual이다.
관절군별 scale은 upper 10°, middle 12°, lower 15°이며 현재 target은:

```text
target = reference + residual_scale * clipped_action
target = clip(target, standing_pose - 60°, standing_pose + 60°)
```

MX upper가 current control을 지원하지 않으므로 18개 joint에 공통으로 적용할
수 있는 position residual을 선택했다. ±60° clip은 실제 hard stop 측정값이
아닌 임시 보수 제한이다.

### 13.3 observation

현재 관측은 70차원이다.

| 항목 | 차원 |
|---|---:|
| body linear velocity | 3 |
| body angular velocity | 3 |
| projected gravity | 3 |
| joint position offset | 18 |
| joint velocity | 18 |
| previous action | 18 |
| normalized command | 3 |
| gait phase sin/cos | 2 |
| heading error sin/cos | 2 |

`policy_compat.py`는 과거 68차원 checkpoint를 재생할 때만 마지막 heading
2개를 잘라 준다. 학습 재개에는 이 adapter를 사용하지 않는다.

### 13.4 reference motion

- `hardcoded`: 기존 사인파 upper stride + middle lift
- `tripod-gait`: model-based alternating tripod + IK
- `scone-gait`: bounded position rolling/creep reference
- `non_rl`: `tripod-gait`의 저장 호환 alias

새 check/train의 기본은 `tripod-gait`이고, `enjoy`와 interactive replay의
기본은 기존 checkpoint를 위해 `hardcoded`다. checkpoint가 학습된 reference를
모르면 저장된 run 설정과 log를 먼저 확인한다. 임의 선택으로 움직임을
“고치려” 하면 policy residual과 reference가 반대 방향으로 상쇄될 수 있다.

### 13.5 reward와 종료

`RewardConfig`는 다음 네 합성군을 만든다.

- `velocity`: command linear tracking과 idle velocity
- `direction`: yaw rate와 누적 target heading
- `stability`: upright, one-sided height drop, oscillation, slip, joint limit,
  forbidden collision
- `damping`: action rate/magnitude, idle residual, estimated current

각 항은 `control_dt`를 곱해 policy frequency 변화에 덜 민감하게 합산한다.
NaN/Inf, 과도한 tilt/height drop, forbidden floor collision, hard joint offset은
episode를 종료하고 termination penalty를 더한다.

reward의 전체 수식과 double-count 방지 규칙은
[`06-reward-function-guide.md`](06-reward-function-guide.md)를 따른다.

### 13.6 RL 기능 수정 방법

reward weight만 바꿀 때:

1. `RewardConfig`의 한 family만 수정
2. `_reward()`의 raw term과 합성군에서 중복 합산되지 않는지 확인
3. zero/random action `check`로 finite와 항별 부호 확인
4. TensorBoard에서 전체 reward뿐 아니라 `reward/*` 항을 비교
5. 기존 checkpoint fine-tune인지 새 실험인지 명시

observation을 바꿀 때:

1. `_observation()` 순서와 `observation_space.shape`를 같이 수정
2. normalization 단위를 문서화
3. 기존 policy는 원칙적으로 새 학습 대상으로 분리
4. replay adapter가 수학적으로 안전한 prefix/suffix 변화일 때만
   `policy_compat.py`에 명시적으로 추가

action/reference를 바꿀 때:

1. `_apply_action()` 합성 의미와 residual scale 수정
2. reference별 zero-action pose를 검증
3. neutral command에서 residual이 사라지는지 확인
4. 기존 checkpoint와 호환되지 않으면 새 run 이름/metadata 사용

physics/controller/terrain/standing pose를 바꿀 때도 environment version이
바뀐 것으로 취급한다.

---

## 14. RL 조종, 학습과 checkpoint 운영

### 14.1 interactive PPO 조종

[`run_rl_joystick()`](../src/rl/joystick_control.py)은 checkpoint ZIP을 검사하고
`SconeWalkEnv(render_mode="human")`를 만든 뒤 policy를 50 Hz로 실행한다.
terminal input은 mailbox에 최신 command를 쓰고 physics/policy loop가 읽는다.

`NeutralResidualGate`는 command가 neutral이면 새 policy bias를 무시하고 이전
residual을 0.10초로 감쇠한다. `R`을 누르면 `_RLModeRouter`가 PPO Walk를
중지하고 같은 `MuJoCoController`에서 Legacy Drive/Climb을 실행한다. Walk로
돌아오면 heading, reference height, action과 gait state를 다시 맞춘다.

### 14.2 PPO 학습

`walk_learn.py train`은 environment 수가 1이면 `DummyVecEnv`, 2개 이상이면
`SubprocVecEnv`를 사용한다. 새 PPO의 현재 주요 hyperparameter는:

- MLP policy/value `[256, 256]`
- learning rate `3e-4`
- `n_steps=1024`, `batch_size=256`, `n_epochs=10`
- `gamma=0.99`, `gae_lambda=0.95`, `clip_range=0.2`
- `ent_coef=0.005`, `max_grad_norm=1.0`

`PruningCheckpointCallback`은 최근 checkpoint 수를 제한하고 resume pointer를
갱신한다. SIGINT/SIGTERM은 현재 step을 마친 뒤 final model과 pointer를
남기는 graceful stop 경로를 사용한다.

hyperparameter를 수정할 때는 reward/environment 변경과 같은 run에 섞지 않는
것이 비교에 유리하다. `n_steps`는 environment당 rollout 길이이고
`checkpoint_every`는 전체 timestep 기준이므로 `num_envs`와 함께 해석한다.

### 14.3 원격 학습 관리

[`inquiry.py`](../src/rl/inquiry.py)는 다음 흐름을 제공한다.

- standing pose, reference, curriculum, terrain, env 수 선택
- 로컬 환경 check
- SSH project sync와 dependency check/install
- 원격 capacity 확인과 env 수 추천
- background launch/status/pause/resume/reset
- artifact download와 local viewer/watch

reset은 기존 run을 즉시 삭제하지 않고 backup으로 이동한다. pause/resume은
`resume.json` 또는 가장 최신의 정상 checkpoint를 찾는다.

[`remote_watch.py`](../src/rl/remote_watch.py)의 mirror는 다음 순서를 지킨다.

1. 최신 step 후보 선택
2. `.part`로 다운로드
3. PPO ZIP 구조 검사
4. 정상 파일만 atomic replace
5. viewer policy hot-swap

미완성 `.part` 또는 손상 ZIP으로 known-good local checkpoint를 덮어쓰지
않는다.

### 14.4 checkpoint 호환성 체크리스트

학습 재개 또는 성능 비교 전에 다음을 기록한다.

- observation shape와 순서
- action shape, residual scale, target clip
- reference motion
- standing pose
- terrain/preset/seed
- physics timestep와 frame skip
- motor spec/PID/profile
- reward config
- curriculum과 command scale

하나라도 다르면 “같은 policy의 단순 재개”가 아니라 migration 또는 새
실험일 수 있다.

---

## 15. 코드 수정 시나리오별 절차

### 15.1 보행 속도 또는 보폭 변경

1. 대상이 Legacy, non-RL MuJoCo, RL reference 중 무엇인지 구분한다.
2. Legacy면 `MotionProfile`과 `walk.py`, non-RL이면
   `TRIPOD_GAIT_SIMULATION_CONFIG`, RL이면 `SconeWalkEnv`의 reference config를
   수정한다.
3. `v * duty / frequency`와 workspace 상한으로 clipping을 계산한다.
4. IK, profile lag, root displacement, drift/yaw/height를 측정한다.
5. 실물 경로를 바꿨으면 지지대·저속 검증을 별도로 수행한다.

### 15.2 새로운 gait 추가

1. 입력과 출력 계약을 `VelocityCommand → motor target/velocity`로 정의한다.
2. pure planner는 `src/locomotion/`, MuJoCo 전용 actuator adapter는
   `src/simulation/core/`에 둔다.
3. 새 config dataclass에 단위와 범위 validation을 둔다.
4. neutral frame과 `stop()`의 zero command를 먼저 구현한다.
5. CLI enum/picker/route를 연결한다.
6. planner 단위 테스트와 floating-base 동역학 회귀를 분리한다.
7. RL reference로 쓸 경우 position residual과 checkpoint version을 별도로
   설계한다.

### 15.3 계단 알고리즘 변경

1. riser/tread/nosing 가정과 geometry predicate를 명시한다.
2. hardcoded baseline을 유지해 같은 환경에서 비교한다.
3. state transition과 actuator target을 단위 테스트한다.
4. headless benchmark에서 성공 여부뿐 아니라 시간, work, upright, contact,
   phase sync/spread를 비교한다.
5. viewer에서 조기 timeout, 전복, lateral escape를 확인한다.
6. 실패 후보도 `docs/11` 또는 `docs/12`에 남긴다.

### 15.4 reward 변경

1. [`06-reward-function-guide.md`](06-reward-function-guide.md)의 현재 수식을
   먼저 갱신한다.
2. 한 reward family만 변경한다.
3. environment check와 reward regression test를 실행한다.
4. old/new run을 분리하고 TensorBoard 항별 변화를 비교한다.
5. checkpoint 재개가 의도된 fine-tune인지 새 baseline인지 적는다.

### 15.5 기존 PPO가 이상하게 움직일 때

코드를 바로 바꾸기 전에 다음 순서로 재현한다.

1. ZIP 무결성 및 observation/action shape
2. 학습 당시 reference motion
3. standing pose
4. terrain/seed와 command
5. current motor profile/PID/physics
6. neutral gate 적용 여부
7. raw policy와 gated replay 비교

특히 학습 당시 `hardcoded` checkpoint에 `tripod-gait`나 `scone-gait`
reference를 선택하지 않는다. 반대 방향 reference와 residual이 합쳐져 보행이
상쇄되거나 뒤틀릴 수 있다.

### 15.6 simulation 기능을 실물로 옮길 때

1. simulation-only type check와 opt-in 경계를 유지한 새 experimental path를
   만든다.
2. actual joint hard stop, 방향, zero, velocity unit을 한 motor씩 측정한다.
3. 전류·온도·통신 timeout·낙상·비상 정지 제한을 구현한다.
4. 지지대에서 낮은 speed와 작은 stroke로 검증한다.
5. 한 tripod contact, 전체 support, 평지, 낮은 장애물 순으로 범위를 넓힌다.
6. MuJoCo 수치를 실물 보증값으로 복사하지 않는다.

---

## 16. 검증 명령과 완료 기준

### 16.1 정적·자동 검증

저장소 root에서 실행한다.

```bash
python -m compileall -q SCONE.py src tests
python -m unittest discover -s tests -v
```

영역별 빠른 테스트:

```bash
python -m unittest tests.test_api tests.test_actuators -v
python -m unittest tests.test_kinematics tests.test_tripod_gait -v
python -m unittest tests.test_scone_gait tests.test_scone_rolling_gait -v
python -m unittest tests.test_stair_geometry tests.test_stair_climber tests.test_stair_demo -v
python -m unittest tests.test_remote_watch tests.test_rl_inquiry tests.test_rl_joystick -v
```

RL environment smoke:

```bash
python -m src.rl.walk_learn \
  --terrain flat \
  --reference-motion tripod-gait \
  check --steps 500 --curriculum easy
```

계단 headless 비교:

```bash
python -m src.simulation.stair_benchmark --all --tuning
```

### 16.2 GUI 검증

macOS viewer는 main-thread 제약 때문에 `mjpython`으로 실행한다.

```bash
mjpython -m src.simulation --control tripod-gait --terrain flat
mjpython -m src.simulation --control scone-gait --terrain flat
mjpython -m src.simulation --control scone-stair --terrain stairs-3
mjpython -m src.simulation --demo compare --terrain stairs-3
```

자동 테스트 통과는 GUI 장시간 접촉 거동을 증명하지 않는다. gait/terrain/
controller를 바꿨다면 다음을 사람이 확인한다.

- 시작 자세에서 폭발적 transient가 없는가
- 명령과 실제 이동 방향이 같은가
- 앞으로 가는 동안 반복적으로 후퇴하지 않는가
- body yaw와 lateral drift가 누적되지 않는가
- 세 다리 지지 전환에서 차체가 과도하게 내려가지 않는가
- C자 opening이 동시에 접지해 지지가 사라지지 않는가
- 종료/Space/Q에서 lower velocity가 0이 되는가

### 16.3 문서 변경 완료 기준

기능을 바꾼 commit에는 최소한 다음을 남긴다.

- 변경한 config와 단위
- 적용 범위: 하드웨어/공용/simulation-only/RL-only
- checkpoint 호환 여부
- 실행한 테스트와 수치
- 실패한 시도와 기각 이유
- 남은 실물/GUI/장기 검증 한계

파일·변수 위치를 찾을 때는
[`05-file-and-folder-map.md`](05-file-and-folder-map.md)와
[`variables/README.md`](variables/README.md), 실행 명령은
[`07-running-testing-and-operations.md`](07-running-testing-and-operations.md)를
함께 사용한다.

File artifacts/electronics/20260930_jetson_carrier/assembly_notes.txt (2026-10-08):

E10 — 젯슨 나노 후면 전자보드 거치대
기준: MARC v4 Body v5 BOX v21. 팬 반대편(+Y)에 장착.

구성
P1: 앞 MX28 상부 M2.5 4개와 기존 젯슨 상단 M3 2개를 연결하는 고정 프레임.
P2: 위로 탈착하는 보드 플레이트. 두 M2.5 나사와 아래쪽 위치결정 돌기로 고정.
P3: 전원 PCB용 4.85 mm 절연 스페이서 4개.
P4: U2D2 선반. UART / TTL / RS485 통신 포트는 위쪽, USB는 전방(+X) 접근.
ROBOTIS PHB: 전원 입력 단자를 위로 향하게 회전한 공식 STEP 형상.
전원 PCB: 70 × 50 × 1.6 mm 기구 검토용 외곽. BMS/충전/12V·5V 전원회로 자체를 설계한 것은 아님.
PCB 기준 홀: 62 × 42 mm, Ø3.2. 플레이트 장공은 높이 ±2 mm 조절 가능.
PCB 부품 공간: 기판 전면에서 15 mm까지 검토. 최종 PCB와 커넥터는 이 공간에 맞춰 설계.

체결품
- P1 → 앞 MX28 상부: M2.5 × 8 소켓헤드 4개. 기존 나사를 교체. 머리 Ø5.4, 깊이 2.7 카운터보어.
- P1 → 젯슨 상단: M3 × 12 소켓헤드 2개. 기존 클립을 유지한 채 함께 조임. 머리 Ø6.4, 깊이 3.2 카운터보어.
- P2 → P1: M2.5 × 8 소켓헤드 2개 + M2.5 너트 2개. 너트는 프레임 상부 측면 포켓에 미리 삽입.
- PHB → P2: M3 × 12 4개 + M3 너트 4개. 플레이트 뒤 포켓에 너트 삽입.
- 전원 PCB → P2: M3 × 12 4개 + M3 너트 4개 + 절연 스페이서 4개.
- P4 → P2: M3 × 8 소켓헤드 2개 + M3 너트 2개.
- U2D2 → P4: M2 × 5 소켓헤드 4개. 케이스 나사 체결 길이 약 3.6 mm. 공식 케이스의 탭을 사용.

조립
1. 전원을 분리하고 상부 손잡이와 팔이 장착된 앞쪽 덮개를 조립체 단위로 분리한다. 팔 자체는 분해하거나 수정하지 않는다.
2. P1의 M2.5 너트 2개를 삽입한다. 앞 MX28 상부 M2.5 4개와 젯슨 상단 M3 2개로 P1을 고정한다.
3. 몸체 밖에서 P2에 너트, PHB, 전원 PCB, P4와 U2D2를 조립하고 배선을 연결한다.
4. 조립한 P2를 위에서 내려 아래 돌기 2개를 홈에 끼운 뒤 위쪽 M2.5 2개로 고정한다.
5. 케이블은 플레이트 타이 홀로 고정한다. PHB 전원 입력은 검토한 직각 플러그 공간을 사용한다.
6. 손잡이와 덮개를 복원한다. 정비 시 위쪽 2개 나사를 풀고 보드 플레이트를 위로 들어낸다.

출력/조립 주의
출력 부품 7개. 나사 카운터보어와 너트 포켓은 실제 형상에 포함된다.
치수는 mm. 프레임 및 플레이트 기본 두께 4 mm, 보드 뒤 간격 4.85 mm.
설치 전에 출력 오차에 따른 나사/너트 끼움만 확인한다. 기존 몸체나 젯슨 거치대에 추가 구멍을 뚫지 않는다.
형상 간섭과 조립 경로 검토이며, 진동·충격 시험 또는 구조 해석 결과는 아님.

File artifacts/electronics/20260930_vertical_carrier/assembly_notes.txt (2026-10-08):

후방 전장 세로 거치대 E9 — 2026-09-30

범위
MARC v4 Body v5 BOX v19에 E9 구성요소만 추가했다. 기존 몸체, 팔, 다리, 젯슨 거치대, 라이다 및 기존 전장 모형의 형상·배치·표시 상태를 보존한다.
전원 PCB는 BMS·충전·12V/5V 전원 분배 회로를 수용할 기구 외곽 모형이다. 회로, 발열, 전류 용량을 설계하거나 검증한 결과물이 아니다.

기구 구성
- P1: 기존 M6R 후방 받침 위에 체결하는 일체형 프레임. 전원 PCB용 세로 판, 장공, 보강 리브, U2D2/PHB 분리판 가이드, 배선 타이 구멍.
- P2: U2D2 + Power Hub Board를 고정하는 탈착식 판. 위로 빼는 구조, M3 너트 삽입 홈, 실제 부품 뒷면 돌출부 회피 공간.
- P3: 상단 고정 클립 2개, M2 나사 머리 카운터보어.
- P4: 전원 PCB 뒷면용 6 mm 절연 스페이서 4개.
- ROBOTIS 공식 U2D2 USB-C 및 PHB STEP 모형을 새 구성요소 안에 배치했다.

전원 PCB 기구 기준
외곽 70 x 50 x 1.6 mm, 모서리 R2.
기준 홀 4개: 지름 3.2 mm, 가로 62 mm x 세로 42 mm 간격.
기준 홀 좌표: PCB 왼쪽 아래에서 (4,4), (66,4), (4,46), (66,46) mm.
스페이서 6 mm. 지지판의 세로 장공으로 홀 높이 조정 가능.
전면 부품 검사용 여유 공간은 폭 58 x 높이 35 x 돌출 20 mm. 이는 부품 선정 완료나 열 설계 검증을 뜻하지 않는다.
PCB 나사 카운터보어: 폭 6.4 mm, 깊이 3.2 mm. 6 mm 지지판의 잔여 두께 2.8 mm.

체결
1. P1 → 기존 M6R: M2.5 x 10 소켓 나사 4개 + M2.5 너트 4개. 기존 2.7 mm 구멍 중 x=-70/-50, y=-40/+40 mm 4곳을 사용. 기존 부품 가공 없음.
   프레임 관통홀 2.8 mm, 머리 자리 5.4 mm, 바닥 잔여 두께 2.9 mm. 받침 아래에서 너트를 잡아 체결.
2. 전원 PCB → P1: M3 x 14 소켓 나사 4개 + M3 너트 4개, P4 스페이서 4개. PCB와 체결부를 먼저 조립한 후 본체에 넣는다.
3. PHB → P2: M3 x 6 나사 4개, 0.5 mm 평와셔 4개, M3 육각 너트 4개. 너트는 P2의 옆 삽입 홈에 먼저 넣는다. 공식 PHB 홀 위치에 맞춘다.
4. U2D2 → PHB: 제조사 플라스틱 리벳 사용. 최신 공식 USB-C 모형을 기준으로 배치했다.
5. P3 클립 → P1: M2 x 8 플라스틱용 나사 2개. 가이드의 1.6 mm 파일럿 홀 사용. 클립 관통 2.2 mm / 머리 자리 4.4 mm 깊이 2.2 mm.

조립 순서
1. 상부 손잡이와 후방 커버/라이다 조립체를 분리해 작업 공간을 확보한다.
2. 전원 PCB를 P1에 스페이서와 함께 미리 체결한다.
3. P1을 기존 M6R 위에 놓고 4개 나사를 위에서, 너트를 아래에서 잡아 조인다.
4. PHB와 U2D2를 P2에 미리 조립한다. 배선을 연결한 뒤 가이드를 따라 위에서 내려 끼운다.
5. P3 상단 클립 2개를 조여 분리판을 고정한다.
6. 배선을 정리하고 커버/라이다와 손잡이를 원래 위치에 조립한다.

커넥터 기준
U2D2 USB-C는 아래 방향이므로 저형 ㄱ자 케이블/커넥터가 필요하다.
예약한 USB 커넥터 공간: 세계 좌표 x=-76..-62, y=26..35.5, z=84.8..90 mm. 하향 외형 약 5 mm 기준이다.
이 공간에 맞는 케이블의 실제 외형·꺾임 방향은 구매 또는 조립 전에 확인해야 한다. 케이블 실물 CAD는 제공되지 않았다.
직선형 DC 배럴 플러그는 맞은편 PCB 판 때문에 연결 공간을 확보하지 않았다. 내부 전원 입력은 PHB 스크루 단자대 배선을 기준으로 한다.

검증 범위
최종 기구 및 공식 전장 모형과 기존 장착물의 솔리드 간섭 검사.
분리판 0/5/10/20/30/40/50/60 mm 상승 위치 검사(손잡이와 후방 커버/라이다 조립체 분리 조건).
베이스 체결용 수직 공구 통로와 지정한 전원 PCB/USB 여유 공간 검사.
기존 172개 구성요소의 형상, 변환, 표시, 재질, 외관 변경 전후 비교.
실물 출력 공차, 케이블 실측, 전기·열·구조 하중 시험은 별도다.

공식 참고 자료
https://en.robotis.com/service/downloadpage.php?ca_id=70
https://en.robotis.com/service/download.php?no=2202 (U2D2 PHB STEP)
https://en.robotis.com/service/download.php?no=2251 (U2D2 STEP)
https://emanual.robotis.com/docs/en/parts/interface/u2d2_power_hub/
https://emanual.robotis.com/docs/en/parts/interface/u2d2/

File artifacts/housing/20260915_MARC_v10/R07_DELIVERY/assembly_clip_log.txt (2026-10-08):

[32;1m
*******************************************************************
******        Statistics on Transfer (Write)                 ******

*******************************************************************
******        Transfer Mode = 0  I.E.  As Is       ******
[0m
[32;1m******        Transferring Shape, ShapeType = 2                      ******
[0m
[32;1m** WorkSession : Sending all data
[0m
[32;1m Step File Name : /Users/hayward_kim/Developer/SCONE/artifacts/housing/20260915_MARC_v10/R07_DELIVERY/outer_master.step(2908 ents)  Write  Done
[0m
[32;1m
*******************************************************************
******        Statistics on Transfer (Write)                 ******

*******************************************************************
******        Transfer Mode = 0  I.E.  As Is       ******
[0m
[32;1m******        Transferring Shape, ShapeType = 2                      ******
[0m
[32;1m** WorkSession : Sending all data
[0m
[32;1m Step File Name : /Users/hayward_kim/Developer/SCONE/artifacts/housing/20260915_MARC_v10/R07_DELIVERY/assembly_clip.step(3834 ents)  Write  Done
[0m
[32;1m
*******************************************************************
******        Statistics on Transfer (Write)                 ******

*******************************************************************
******        Transfer Mode = 0  I.E.  As Is       ******
[0m
[32;1m******        Transferring Shape, ShapeType = 0                      ******
[0m
[32;1m** WorkSession : Sending all data
[0m
[32;1m Step File Name : /Users/hayward_kim/Developer/SCONE/artifacts/housing/20260915_MARC_v10/R07_DELIVERY/assembly_shell_unused.step(6780 ents)  Write  Done
[0m

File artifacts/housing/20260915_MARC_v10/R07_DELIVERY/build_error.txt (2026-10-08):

Traceback (most recent call last):
  File "<string>", line 97, in <module>
  File "<string>", line 87, in build
  File "<string>", line 6, in cut
  File "<string>", line 14, in cut
  File "<string>", line 11, in boolean
  File "/Users/hayward_kim/Library/Application Support/Autodesk/webdeploy/production/127ae56f1790f40cf393bcc73875a1a281e20234/Autodesk Fusion.app/Contents/Api/Python/packages/adsk/fusion.py", line 75852, in booleanOperation
    return _fusion.TemporaryBRepManager_booleanOperation(self, targetBody, toolBody, booleanType)
           ~~~~~~~~~~~~~~~~~~~~~~~~~~~~~~~~~~~~~~~~~~~~~^^^^^^^^^^^^^^^^^^^^^^^^^^^^^^^^^^^^^^^^^
RuntimeError: 3 : ASM_FACE_BOUNDARY - wire being deleted crosses face boundary

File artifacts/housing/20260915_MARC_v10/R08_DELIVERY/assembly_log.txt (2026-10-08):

[32;1m
*******************************************************************
******        Statistics on Transfer (Write)                 ******

*******************************************************************
******        Transfer Mode = 0  I.E.  As Is       ******
[0m
[32;1m******        Transferring Shape, ShapeType = 2                      ******
[0m
[32;1m** WorkSession : Sending all data
[0m
[32;1m Step File Name : /Users/hayward_kim/Developer/SCONE/artifacts/housing/20260915_MARC_v10/R08_DELIVERY/outer_master.step(2908 ents)  Write  Done
[0m
[32;1m
*******************************************************************
******        Statistics on Transfer (Write)                 ******

*******************************************************************
******        Transfer Mode = 0  I.E.  As Is       ******
[0m
[32;1m******        Transferring Shape, ShapeType = 2                      ******
[0m
[32;1m** WorkSession : Sending all data
[0m
[32;1m Step File Name : /Users/hayward_kim/Developer/SCONE/artifacts/housing/20260915_MARC_v10/R08_DELIVERY/assembly_clip.step(3890 ents)  Write  Done
[0m
[32;1m
*******************************************************************
******        Statistics on Transfer (Write)                 ******

*******************************************************************
******        Transfer Mode = 0  I.E.  As Is       ******
[0m
[32;1m******        Transferring Shape, ShapeType = 0                      ******
[0m
[32;1m** WorkSession : Sending all data
[0m
[32;1m Step File Name : /Users/hayward_kim/Developer/SCONE/artifacts/housing/20260915_MARC_v10/R08_DELIVERY/assembly_shell_unused.step(6858 ents)  Write  Done
[0m

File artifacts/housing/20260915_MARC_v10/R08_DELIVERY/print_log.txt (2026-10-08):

[
  {
    "part": "R01 Rear smooth PLA chassis",
    "filename": "R01_PLA_mm.stl",
    "quantity": 1,
    "material": "PLA",
    "orientation": "Lower planar face on bed",
    "dimensions_mm": [
      144.4,
      138.0,
      36.8
    ],
    "fits_256mm": true,
    "triangles": 9800,
    "nonmanifold_edge_count": 12,
    "mesh_volume_error_pct": 0.0003357136307613473,
    "native_lumps": 1
  },
  {
    "part": "R02 Front smooth PLA chassis",
    "filename": "R02_PLA_mm.stl",
    "quantity": 1,
    "material": "PLA",
    "orientation": "Lower planar face on bed",
    "dimensions_mm": [
      162.45,
      154.0,
      81.5
    ],
    "fits_256mm": true,
    "triangles": 13848,
    "nonmanifold_edge_count": 12,
    "mesh_volume_error_pct": 0.00037058908480824826,
    "native_lumps": 1
  },
  {
    "part": "S01 Rear fairing lid",
    "filename": "S01_PLA_mm.stl",
    "quantity": 1,
    "material": "PLA",
    "orientation": "Flat exterior/top face on bed, part upside down",
    "dimensions_mm": [
      144.25,
      154.0,
      70.2
    ],
    "fits_256mm": true,
    "triangles": 3000,
    "nonmanifold_edge_count": 0,
    "mesh_volume_error_pct": 0.0031204966923881194,
    "native_lumps": 1
  },
  {
    "part": "S02 Front camera fairing lid",
    "filename": "S02_PLA_mm.stl",
    "quantity": 1,
    "material": "PLA",
    "orientation": "Flat exterior/top face on bed, part upside down",
    "dimensions_mm": [
      144.45001,
      154.0,
      70.2
    ],
    "fits_256mm": true,
    "triangles": 3744,
    "nonmanifold_edge_count": 0,
    "mesh_volume_error_pct": 0.014552240249721127,
    "native_lumps": 1
  },
  {
    "part": "P04 PLA electronics tray",
    "filename": "P04_PLA_mm.stl",
    "quantity": 1,
    "material": "PLA",
    "orientation": "Lower planar face on bed",
    "dimensions_mm": [
      99.276,
      128.0,
      12.9
    ],
    "fits_256mm": true,
    "triangles": 1372,
    "nonmanifold_edge_count": 0,
    "mesh_volume_error_pct": 0.005016538002977633,
    "native_lumps": 1
  },
  {
    "part": "M01 Rear removable motor bridge",
    "filename": "M01_PLA_mm.stl",
    "quantity": 1,
    "material": "PLA",
    "orientation": "Flat exterior/top face on bed, part upside down",
    "dimensions_mm": [
      39.5087,
      86.0,
      7.7
    ],
    "fits_256mm": true,
    "triangles": 1692,
    "nonmanifold_edge_count": 0,
    "mesh_volume_error_pct": 0.06238656482879801,
    "native_lumps": 1
  },
  {
    "part": "M02 Front removable motor bridge",
    "filename": "M02_PLA_mm.stl",
    "quantity": 1,
    "material": "PLA",
    "orientation": "Flat exterior/top face on bed, part upside down",
    "dimensions_mm": [
      39.49129,
      86.0,
      7.7
    ],
    "fits_256mm": true,
    "triangles": 1690,
    "nonmanifold_edge_count": 0,
    "mesh_volume_error_pct": 0.05557619458858021,
    "native_lumps": 1
  },
  {
    "part": "L11 separate 5mm LINK plate",
    "filename": "L11_PLA_mm.stl",
    "quantity": 2,
    "material": "PLA",
    "orientation": "5mm plate flat on bed, hole axes vertical",
    "dimensions_mm": [
      123.75,
      38.2,
      5.0
    ],
    "fits_256mm": true,
    "triangles": 1120,
    "nonmanifold_edge_count": 0,
    "mesh_volume_error_pct": 0.04187839650913183,
    "native_lumps": 1
  },
  {
    "part": "L12 separate 5mm LINK plate",
    "filename": "L12_PLA_mm.stl",
    "quantity": 2,
    "material": "PLA",
    "orientation": "5mm plate flat on bed, hole axes vertical",
    "dimensions_mm": [
      123.75,
      38.2,
      5.0
    ],
    "fits_256mm": true,
    "triangles": 1120,
    "nonmanifold_edge_count": 0,
    "mesh_volume_error_pct": 0.041878396509242855,
    "native_lumps": 1
  },
  {
    "part": "L21 separate 5mm LINK plate",
    "filename": "L21_PLA_mm.stl",
    "quantity": 2,
    "material": "PLA",
    "orientation": "5mm plate flat on bed, hole axes vertical",
    "dimensions_mm": [
      123.75,
      38.2,
      5.0
    ],
    "fits_256mm": true,
    "triangles": 1120,
    "nonmanifold_edge_count": 0,
    "mesh_volume_error_pct": 0.04187839650937608,
    "native_lumps": 1
  },
  {
    "part": "L22 separate 5mm LINK plate",
    "filename": "L22_PLA_mm.stl",
    "quantity": 2,
    "material": "PLA",
    "orientation": "5mm plate flat on bed, hole axes vertical",
    "dimensions_mm": [
      123.75,
      38.2,
      5.0
    ],
    "fits_256mm": true,
    "triangles": 1120,
    "nonmanifold_edge_count": 0,
    "mesh_volume_error_pct": 0.04187839650942049,
    "native_lumps": 1
  },
  {
    "part": "T01 TPU tyre 20mm",
    "filename": "T01_TPU_mm.stl",
    "quantity": 2,
    "material": "TPU",
    "orientation": "Lower planar face on bed",
    "dimensions_mm": [
      144.95559,
      244.96172,
      20.0
    ],
    "fits_256mm": true,
    "triangles": 960,
    "nonmanifold_edge_count": 0,
    "mesh_volume_error_pct": 0.03461664646193796,
    "native_lumps": 1
  },
  {
    "part": "W01 PLA rim 18mm seat, original hub",
    "filename": "W01_PLA_mm.stl",
    "quantity": 2,
    "material": "PLA",
    "orientation": "Lower planar face on bed",
    "dimensions_mm": [
      124.97085,
      225.0,
      18.0
    ],
    "fits_256mm": true,
    "triangles": 1888,
    "nonmanifold_edge_count": 0,
    "mesh_volume_error_pct": 0.013618937179804558,
    "native_lumps": 1
  },
  {
    "part": "T11 TPU tyre 20mm",
    "filename": "T11_TPU_mm.stl",
    "quantity": 2,
    "material": "TPU",
    "orientation": "Lower planar face on bed",
    "dimensions_mm": [
      144.95559,
      244.96172,
      20.0
    ],
    "fits_256mm": true,
    "triangles": 960,
    "nonmanifold_edge_count": 0,
    "mesh_volume_error_pct": 0.03461664646223772,
    "native_lumps": 1
  },
  {
    "part": "W11 PLA rim 18mm seat, original hub",
    "filename": "W11_PLA_mm.stl",
    "quantity": 2,
    "material": "PLA",
    "orientation": "Original hub mounting face on bed, 18mm seat upward",
    "dimensions_mm": [
      124.97085,
      225.0,
      18.0
    ],
    "fits_256mm": true,
    "triangles": 1888,
    "nonmanifold_edge_count": 0,
    "mesh_volume_error_pct": 0.013530955223484131,
    "native_lumps": 1
  }
]

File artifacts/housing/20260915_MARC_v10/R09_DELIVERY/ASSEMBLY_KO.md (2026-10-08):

# MARC Housing PLA R09 — 구조 단순화와 조립 안내

최종 전달 모델은 **MARC Housing PLA R09 Assembled**다. R09 작업 중 분리해 둔 덮개 배치는 기존 R09와 별도 백업에 보관하고, 전달용 복사본의 덮개만 원래 조립 위치에 맞췄다. R09는 R08을 복사한 독립 작업 모델이며 사용자 원본 MARC v11과 FR07을 수정하지 않는다. 이 문서는 CAD 조립 검토와 출력용 형상을 설명하며, 실물 강도·열·피로 검증 완료를 뜻하지 않는다.

## 이번 변경

- 상부 외피를 깨끗한 면에서 다시 구성하고, 반복 수정 과정의 불필요한 내부 형상을 제거했다.
- 지붕 통풍 슬롯을 7줄에서 3줄로 통합했다. 설계 개방 면적 1,050 mm²는 유지한다. 측면 슬롯은 14개에서 4개로 줄이고 설계 개방 면적은 546 → 636 mm²로 확보했다. 면적 비교는 냉각 성능 시험 결과가 아니다.
- 하부의 폐기된 구멍 6개를 메웠다. 좌표는 X142/Y±30, X168/Y±32, X180/Y±30 mm다. 인접한 실제 덮개 볼트의 머리 공간은 다시 가공해 유지했다.
- MX28 하부의 복잡한 케이스 모양 홈은 단순한 사각 개구부로 정리했다. 실제 모터 돌출부를 피하기 위해 필요한 공간이며, 네 개의 기존 볼트 축과 지지 면은 유지했다.
- 덧붙은 바닥에 막혀 있던 배선 고정 슬롯을 X0/Y±19 및 X158/Y±19에서 다시 열었다. 배터리 스트랩 슬롯과 기존 TTL 배선 통로는 유지한다.
- 전체 앞뒤 길이 289 mm, 상·하부 공통 외곽, 작은 R1 외부 모서리, 기존 분할선과 조립 위치를 유지했다.
- 스테레오 카메라 지지대를 단순한 기둥으로 정리하고, 기판 부품 주변에는 필요한 최소 여유만 두었다.

FR07, 모터 축 위치, 122.5 mm 링크 길이, 두 개의 5 mm LINK 평판, 바퀴의 반원 형상은 변경하지 않았다. R08에서 확장한 TPU 타이어 폭 20 mm와 PLA 림 좌석 폭 18 mm를 유지한다. 림의 기존 허브 결합부는 원래 두께 10 mm다.

## 부품과 출력

`PRINT_PACKAGE`의 STL은 mm 단위이며 바닥에 놓이는 방향으로 정렬한다. STEP은 설계 좌표를 유지한다. 전체 F3D에는 기존 조립체와 숨겨 둔 설계 이력이 포함된다. 출력은 최종 STL 목록을 기준으로 한다.

| 부품 | 수량 | 재료 | 배치 |
|---|---:|---|---|
| R01/R02 하부 프레임 | 각 1 | PLA | 평평한 바닥을 베드에 배치 |
| S01/S02 상부 덮개 | 각 1 | PLA | 평평한 지붕을 베드에 배치 |
| P04 전자부품 트레이 | 1 | PLA | 트레이 바닥을 베드에 배치 |
| M01/M02 분리형 모터 브리지 | 각 1 | PLA | 상면을 베드에 배치 |
| L11/L12/L21/L22 LINK 평판 | 각 2 | PLA | 5 mm 평판을 눕혀 배치 |
| W01/W11 림 | 각 2 | PLA | 기존 허브 장착면을 베드에 배치 |
| T01/T11 타이어 | 각 2 | TPU | 평평한 축 방향 면을 베드에 배치 |

총 15종, 23개이며 FR07과 구매 부품은 이 목록에서 제외한다. 분할한 모든 부품은 256 mm 출력 범위에 들어가도록 검사한다. 타이어의 가장 긴 방향은 약 245 mm이므로 256 mm 베드에서는 3 mm 브림을 사용한 배치까지 확인하고, 과도하게 넓은 브림은 피한다. 지지대와 브리지 가능 여부는 선택한 프린터의 슬라이서에서 확인한다.

## 예시 나사

사용자가 최종 나사 규격을 나중에 제공하기로 했으므로 아래는 현재 CAD 검사용 예시다. 실제 나사 머리, 와셔, 인서트, 모터 나사산 깊이를 대조한 뒤 확정한다. 모터 내부로 돌출되는 길이를 임의로 늘리지 않는다.

| 결합부 | 예시 규격 | 수량 | 접근 방향/조립 조건 |
|---|---|---:|---|
| 상·하부 덮개 | M3×35, 낮은 머리 Ø6×2.5 | 8 | 몸체 아래에서 축 방향 |
| 하부 앞뒤 겹침 이음 | M4×25 + 너트·와셔 | 4 | 트레이를 떼고 아래 드라이버/위 너트 공구 |
| MX28 케이스 상부 | M2×6 | 16 | 덮개·다리 조립 전 위에서 |
| MX28 케이스 하부 | M2×4 | 16 | 다리·바퀴 조립 전 아래에서 |
| 분리형 모터 브리지 | M3×8, 낮은 머리 Ø5.5×2 | 4 | 위에서 |
| 전자부품 트레이 | M3×10, 낮은 머리 Ø5.5×2 | 4 | Jetson을 넣기 전 위에서 |
| Jetson 고정 탭용 자리 | M3×6 | 4 | Ø3.5 이하의 가는 드라이버 축 |
| 스테레오 카메라 | M2×5 | 4 | 분리한 앞 덮개의 뒤쪽에서 |
| T-mini Plus | M2×5 | 2 | 분리한 뒤 덮개 안쪽에서 |

덮개 및 브리지용 M3 인서트는 예시 외경 4.6 mm/길이 5 mm, 현재 파일의 파일럿 구멍은 Ø4.0 mm다. 카메라는 예시 M2 인서트 외경 3.2 mm/길이 3 mm에 Ø3.0 mm 파일럿을 사용한다. 트레이·Jetson 탭용 자리에는 Ø2.5 mm 파일럿이 있다. 최종 인서트 제조사와 실제 출력 수축에 맞춰 시험편으로 확인한다. 위 수량은 하우징 관련 예시이며 공장 부품, LINK 및 휠 체결품을 포함하는 전체 구매 BOM이 아니다.

## 조립 순서

1. 출력물의 지지재와 홀 내부를 정리하고 인서트·너트 자리를 확인한다.
2. R01/R02 하부를 겹침 이음으로 연결한다. 트레이가 없는 상태에서 M4 드라이버와 너트 공구를 수직으로 넣는다.
3. M01/M02 브리지를 분리한 상태에서 MX28 케이스를 위로 넣는다. 아래쪽 케이스 나사를 먼저 조립하고, 브리지와 위쪽 케이스 나사를 체결한다. 다리·바퀴는 공구 접근이 끝난 뒤 연결한다.
4. 배터리, PCB, U2D2와 고정 배선을 배치한다. 배터리 스트랩과 배선 고정 슬롯을 이용하고, 트레이 아래 통로로 TTL 배선을 지나가게 한다.
5. P04를 조립한 뒤 Jetson을 둔다. Jetson 고정 탭의 실제 형상·접촉면과 구매 나사 머리는 아직 실물 확인 및 확정이 필요하다. 기기 자체에 새 장착 구멍이 있다고 가정하지 않는다.
6. S02를 분리한 상태에서 카메라를 최종 위치보다 105 mm 뒤쪽에서 아래로부터 넣고, 앞쪽으로 미끄러뜨린다. 뒤쪽에서 카메라 고정 나사를 넣고 FFC를 연결한다. 필요한 작업 방향이 수직이 되도록 덮개를 작업대에서 돌려 놓는다.
7. 분리한 S01 안쪽에서 라이다를 조립하고 케이블을 연결한다. 두 덮개를 덮고 몸체 아래쪽 나사로 결합한다.
8. 다리와 바퀴를 결합한 뒤, 전원을 넣기 전에 케이블 여유와 전체 이동 경로를 수동으로 확인한다.

## 배선·동작 검토 범위

- 3핀 TTL 배선용 고정 통로와 커넥터 개구부를 유지한다. MX28과 XM430의 실제 커넥터에 맞는 하네스를 사용한다. U2D2는 신호 인터페이스이며 모터 전원을 공급하는 장치로 취급하지 않는다.
- 후면 외부 포트는 내부 Jetson까지 이어지는 연장 케이블을 전제로 한다. Jetson 본체 포트에 후면 구멍으로 직접 손을 넣는 구조가 아니다.
- FFC 공간은 예약되어 있지만, 실제 케이블 길이·커넥터 잠금부·최소 굽힘 반경과 움직이는 다리의 서비스 루프는 구매 하네스로 확인해야 한다.
- MX28 안쪽 90°/힙 XM430 180°에서 20 mm 타이어의 전체 회전 공간을 검사한다. 사용자 후방 다리 자세와 그에 이르는 경로도 별도로 검사한다.
- 사용자가 보여준 후방 다리 자세에서 앞다리를 기본 자세에 그대로 두면, 후방 바퀴의 전체 회전 영역이 앞다리 휠과 겹칠 수 있다. 하우징 간섭 제거만으로 임의의 모든 다리 조합을 허용할 수 없으므로 다리 간 동작 조정이 필요하다.
- PLA 구조물의 충격·피로, 인서트 체결력, TPU 변형 및 Jetson 발열은 CAD 공간 검사로 검증되지 않는다. 배터리와 custom PCB는 확정된 구매품 CAD가 아닌 설계용 공간이다.

최종 검사 결과는 같은 폴더의 `VALIDATION_KO.md`와 `PRINT_PACKAGE/print_manifest.json`에서 확인한다.

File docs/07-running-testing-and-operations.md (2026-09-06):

# 실행·학습·운영·검증

## 1. 환경 설치

권장 Python 가상환경에서 실행한다.

```bash
python -m venv .venv
source .venv/bin/activate
python -m pip install --upgrade pip
```

CLI, Dynamixel SDK, MuJoCo, RL 의존성을 하나의 파일에서 설치한다.

```bash
python -m pip install -r requirements.txt
```

아카이브 SCONEv1의 OpenCV/imutils vision 코드는 현재 runtime 의존성이 아니다.

## 2. 통합 launcher

macOS에서 MuJoCo viewer를 열 때는 viewer가 main thread를 사용할 수 있도록 `mjpython`을 권장한다.

```bash
mjpython SCONE.py
```

기본 UI 언어는 영어다. 한국어 메뉴, 시뮬레이션 선택 화면, 조이스틱 HUD,
RL 관리 화면을 사용하려면 다음처럼 실행한다.

```bash
mjpython SCONE.py --language korea
```

정식 값은 `english`, `korea`이며 `en`, `ko`, `korean`도 입력 alias로
허용한다. 언어 옵션은 표시 문구만 바꾸며 menu value, gait 이름, checkpoint,
모터 명령에는 영향을 주지 않는다. 직접 시뮬레이션 진입점도 같은 옵션을 쓴다.

```bash
mjpython -m src.simulation --language korea
```

영어/한국어 메뉴에서 다음 작업을 선택할 수 있다.

- 시뮬레이션 (자동 데모): hardcoded/improved/compare와 stairs-1..3 선택, 조종 입력 없음
- 시뮬레이션 조종: profile, control 방식, terrain, 필요 시 RL checkpoint
- 하드웨어 조종: 탐색된 serial port와 legacy discrete 제어
- 하드웨어 다시 탐색: torque/position을 바꾸지 않는 ping
- 강화학습 관리: 환경 검사, 새 학습, 원격 상태/pause/resume/download/watch/reset

velocity joystick:

| 키 | 동작 |
|---|---|
| `W/S` | 전진/후진 `vx` |
| `A/D` | 좌/우 `vy` |
| 좌/우 화살표 | yaw |
| `Space` | 즉시 neutral |
| `R` | Legacy/RL에서 Walk→Drive→Climb→Walk 전환 |
| `H` | Legacy에서 home 자세 복귀 |
| `Q` | 현재 조종 종료 |

키를 놓은 뒤 terminal key-repeat가 끊기면 약 0.35초 후 해당 축이 자동으로 0이 된다. 종료 시에도 explicit neutral을 전송한다.

## 3. Python API와 실제 하드웨어

최소 예제:

```bash
python example.py
```

코드에서 사용할 때:

```python
import SCONE
from src.hardware import Controller, discover_hardware

probe = discover_hardware()
if probe.available:
    with SCONE.SCONE(Controller(probe.device_name), profile="standard") as robot:
        robot.forward()
        robot.left()
```

안전 확인:

1. 로봇을 지지대에 올리고 비상 전원 차단 수단을 준비한다.
2. ID 1, 7, 13의 모델 응답과 전체 bus 전원을 확인한다.
3. `SCONE_DEVICE` 또는 탐색 결과가 실제 포트인지 확인한다.
4. 처음에는 낮은 speed/제한된 motion으로 각 ID 방향과 zero를 확인한다.
5. `with` 또는 `try/finally`를 사용해 `close()`와 torque-off를 보장한다.
6. RL checkpoint를 실제 controller에 직접 연결하지 않는다. 현재 RL 환경은 MuJoCo body state에 의존한다.

## 4. 시뮬레이션 직접 실행

```bash
mjpython -m src.simulation
```

조종 없이 hardcoded와 improved 계단 동작을 순서대로 보려면:

```bash
mjpython -m src.simulation --demo compare --terrain stairs-2
```

두 방식 모두 여섯 C-frame을 같은 기하 위상으로 정렬한다. hardcoded는 그
전에 앞쪽 1단을 옛 코드의 270° 수직 자세로 만들고 fixed velocity open-loop로
전환한다. improved는 180/184/195° partial brace와 공통 다회전 position
target을 사용한다. 현재 headless에서 hardcoded는 20 cm에 실패하고 improved는
세 높이를 모두 통과한다.
자동 데모는 terminal joystick을 열지 않는다.

argparse option은 다음 명령으로 확인한다.

```bash
python -m src.simulation --help
```

계단 전용 synchronized-phase controller는 SCONE을 자동으로 side-on 자세로 만든다.
`A`는 preset 계단의 `+Y` 상승, `D`는 반대 방향이며 W/S와 yaw는 이 경로에서
비활성화된다.

```bash
mjpython -m src.simulation \
  --control scone-stair \
  --profile standard \
  --terrain stairs-3
```

`scone-stair`는 MuJoCo 전용이다. 실물 적용 전에 후킹 기하, 모터 여유,
마찰과 지지 조건을 [계단 알고리즘 문서](11-scone-stair-climbing.md)대로
별도 계측한다.

연속 회전 비교는 `roll-gait`, PPO/점접지 하이브리드는 `scone-gait`다.
후자는 checkpoint와 그 checkpoint가 학습한 reference/stance가 필요하다.

```bash
mjpython -m src.simulation --control roll-gait --profile standard --terrain flat

mjpython -m src.simulation \
  --control scone-gait \
  --checkpoint runs/walk_full_standard/checkpoints/scone_walk_15410928_steps.zip \
  --rl-reference-motion hardcoded \
  --rl-standing-pose-degrees \
    135 135 180 180 225 225 240 240 240 240 240 240 255 255 255 255 255 255
```

문서의 H0–H4 전체 비교와 H3 튜닝 sweep은 headless로 다시 실행할 수 있다.
출력은 한 실험당 JSON 한 줄이며 상단 성공, 시간, 절대 기계일, upright,
contact force, phase 동기화 횟수, 상단까지의 실제 phase spread를 포함한다.

```bash
python -m src.simulation.stair_benchmark --all --tuning
```

코드에서 모델만 만들 수 있다.

```python
from src.simulation import load_model

model = load_model(
    floating_base=True,
    terrain="mixed",
    terrain_seed=42,
)
```

`flat`, `uneven`, `stairs-1..3`, `slope-1..3`, `mixed`가 지원된다. random rough patch를 비교할 때는 seed를 고정한다.

지형 geom은 viewer 기본 표시 그룹 0에 있고 카메라는 몸체를 추적한다. 긴 `mixed` 코스 때문에 초기 카메라가 과도하게 멀어지지 않도록 거리를 2.2–3.0 범위로 제한한다.

## 5. RL 환경 검사

기본 reference와 보상 finite 여부:

```bash
python -m src.rl.walk_learn --reference-motion tripod-gait \
  check --steps 500 --curriculum easy
```

무작위 residual과 full 명령 범위:

```bash
python -m src.rl.walk_learn check \
  --steps 500 \
  --curriculum full \
  --random-actions
```

지형 option은 subcommand 앞에 둔다.

```bash
python -m src.rl.walk_learn \
  --terrain uneven \
  --terrain-seed 7 \
  --reference-motion scone-gait \
  check \
  --steps 500
```

출력되는 mean weighted reward term은 항의 부호와 scale을 보는 smoke 지표다. 학습 성능 결론으로 사용하지 않는다.

모델 기반 gait 기준을 선택하면 TensorBoard `state/` 아래에 다음 튜닝 지표가 추가된다.

- `reference_cycle_frequency`: 현재 기준 모션 cadence. `tripod-gait`는 `0.7 Hz`, `scone-gait`는 `0.65 Hz`
- `reference_stride_clip_fraction`: 작업공간 한계에 걸린 다리 비율
- `reference_ik_backoff_scale`: IK 재시도로 실제 적용된 발 오프셋 배율. 항상 1보다 작다면 stance·보폭을 다시 조정한다.

## 6. PPO 학습

새 82차원 `walk_v2` 학습은 bounded action과 fixed-command best-model 평가가 적용된
다음 경로를 권장한다. 구형 70차원 `walk_learn` 명령은 기존 checkpoint 호환을 위해
아래에 별도로 남겨 둔다.

```bash
python -m src.rl.walk_v2 --reference-motion tripod-gait --stance standard train \
  --timesteps 50000000 \
  --curriculum easy \
  --num-envs 4 \
  --checkpoint-every 100000 \
  --keep-checkpoints 20 \
  --output runs/walk-v2-bounded-easy \
  --tensorboard-log runs/walk-v2-bounded-easy/tensorboard
```

V2 기본값은 learning rate `1e-4`, 3 epoch, target KL `0.02`, batch 512,
gSDE+tanh squash, 초기 std 약 0.223이다. batch는 `n_steps × num_envs`의 약수여야
한다. 기존 unbounded/clipped V2 checkpoint는 재생할 수 있지만 새 코드로 resume할
수는 없다.

V2 run에는 `best_candidate_model.zip`과 별도로, nominal 여섯 명령에서 zero
residual을 이기고 모든 명령축 방향이 맞을 때만 `best_model.zip`이 생긴다. 세부
평가식과 파일은
[`21-walk-v2-ppo-training-analysis.md`](21-walk-v2-ppo-training-analysis.md)를 따른다.

기존 70차원 정책의 새 학습:

```bash
python -m src.rl.walk_learn --reference-motion tripod-gait train \
  --timesteps 1000000 \
  --curriculum easy \
  --num-envs 4 \
  --checkpoint-every 100000 \
  --keep-checkpoints 10 \
  --output runs/walk_easy_experiment \
  --tensorboard-log runs/tensorboard
```

학습 재개:

```bash
python -m src.rl.walk_learn --reference-motion tripod-gait train \
  --timesteps 1000000 \
  --curriculum easy \
  --num-envs 4 \
  --resume runs/walk_easy_experiment/checkpoints/scone_walk_100000_steps.zip \
  --output runs/walk_easy_experiment
```

재개 전 확인:

- 관측 70차원, action 18차원, 순서가 동일한가
- standing pose와 reference gait 의미가 동일한가
- reward 변경 후 fine-tune인지 완전한 비교 실험인지 구분했는가
- 68차원 legacy policy가 아닌가
- checkpoint ZIP이 완전한가

SIGINT/SIGTERM을 보내면 현재 step을 마치고 final model/resume pointer를 남기는 경로를 사용한다.

`--reference-motion tripod-gait`는 고전 교대 삼각보+IK를 사용한다. `scone-gait`는 여기에 부채꼴 rolling/creep sweep을 더한 실험 기준이며, `hardcoded`는 기존 사인파 tripod를 보존한다. `non_rl`은 `tripod-gait` 호환 별칭이다. 기준 모션이 다른 checkpoint를 재개하면 action 의미가 달라지므로, 원래 설정과 반드시 일치시킨다.

두 gait의 정확한 기본값, reference+residual 합성, checkpoint 호환 표와
튜닝 순서는 [`10-tripod-gait-and-scone-gait.md`](10-tripod-gait-and-scone-gait.md)를
참고한다.
현재 `roll-gait`/hybrid `scone-gait` route와 전환 속도는
[`14-roll-gait-and-hybrid-scone-gait.md`](14-roll-gait-and-hybrid-scone-gait.md)를
우선한다.

`tripod-gait` 기준 모션은 2026-08-31에 stride 작업공간과 IK backoff가 추가되었고, support point는 부채꼴 말단의 최저 0.1 mm 패치 중심으로 교정됐다. RL reference는 checkpoint 의미를 보존해 0.7 Hz, 60/50 mm를 유지한다. 2026-09-01 후속 직진 진단 뒤 비-RL MuJoCo 조종만 1.0 Hz, lift 25 mm, 90/70 mm, profile 무제한, middle hold 2배를 opt-in한다. 기존 PPO도 무제한 simulation profile에서 학습됐으므로 RL reset 동역학은 변하지 않는다. 새 profile/dynamics 학습은 기존 checkpoint를 resume하지 말고 환경 버전을 기록해 0 step부터 시작한다.

`--num-envs 1`은 단일 프로세스이고 2 이상은 `SubprocVecEnv`로 각 MuJoCo 환경을 별도 프로세스에서 실행한다. 환경 수를 늘리면 PPO rollout 크기도 `n_steps × num_envs`로 커지므로 CPU 사용률뿐 아니라 업데이트 지연과 메모리를 함께 확인한다.

## 7. 정책 재생과 조이스틱

고정 명령 재생:

```bash
mjpython -m src.rl.walk_learn --reference-motion tripod-gait enjoy \
  runs/walk_full_standard/checkpoints/scone_walk_6100000_steps.zip \
  --command 0.25 0.0 0.0 \
  --curriculum full \
  --episodes 3
```

실시간 조이스틱은 통합 launcher의 RL control 또는 `src.rl.joystick_control` API를 사용한다. 기본으로 neutral residual gate가 켜진다. `R`을 누르면 policy target을 일시 중단하고 같은 controller에서 Drive/Climb으로 전환하며, Walk 복귀 시 heading·기준 높이·residual 상태를 재정렬한다. `scone-gait`에서는 HUD의 `ppo/mix/hybrid` suffix로 speed supervisor 상태를 확인한다.

68차원 checkpoint는 마지막 heading 두 관측이 없으므로 현재 70차원 관측의 앞 68개를 전달해 재생한다. 이 adapter를 학습 재개에 사용하지 않는다.

## 8. 원격 학습 운영

대화형 진입:

```bash
python -m src.rl
```

일반 흐름:

1. `학습 환경/보상 스모크 테스트`
2. `새 학습 시작`에서 SSH/로컬 위치를 먼저 선택
3. SSH이면 머신의 코어·가용 메모리·load를 조회해 병렬 환경 수 추천 확인
4. reference, curriculum, terrain, stance, timestep, env 수 선택
5. 필요 시 현재 코드를 SSH host로 동기화
6. Python 3.12 `.venv`와 RL 의존성 확인
7. `nohup` background trainer의 PID/로그/checkpoint 확인
8. pause 시 SIGTERM과 resume checkpoint 사용
9. resume 시 같은 run 설정과 호환성 확인
10. watcher/download는 `.part`를 받은 뒤 ZIP 검증과 atomic publish

추천 환경 수는 다음 보수식의 최솟값이다.

```text
CPU 한도 = max(1, 물리 코어 - 1)
메모리 한도 = max(1, floor((가용 메모리 - 2 GiB) / 768 MiB))
추천 = min(CPU 한도, 메모리 한도)
```

자동 조회가 실패하면 4개를 편집 가능한 기본값으로 제안한다. 추천은 “최대 안전 성능”의 보장이 아니라 시작점이며, 원격 머신에 다른 작업이 있으면 실제 FPS와 load를 보고 낮춘다.

`runs/.remote_jobs.json`은 접속/실험 metadata이므로 공개 저장소에 올리기 전에 host/path 정보가 민감하지 않은지 확인한다.

reset은 삭제가 아니라 원격 `runs/.reset_backup/`으로 이동한다. 복구 가능성을 확인한 뒤 오래된 백업을 별도로 정리한다.

## 9. 테스트

전체 테스트:

```bash
python -m unittest discover -s tests -v
```

영역별 빠른 실행:

```bash
python -m unittest tests.test_actuators tests.test_api
python -m unittest tests.test_kinematics tests.test_tripod_gait tests.test_scone_gait
python -m unittest tests.test_stair_geometry tests.test_stair_climber
python -m unittest tests.test_simulation tests.test_terrain
python -m unittest tests.test_remote_watch tests.test_rl_inquiry
python -m unittest tests.test_rl_joystick tests.test_rl_reference_motion
python -m unittest tests.test_walk_v2 tests.test_walk_v3
python -m unittest tests.test_walk_failsafe
```

변경별 최소 검증:

| 변경 영역 | 최소 테스트 |
|---|---|
| actuator ID/register | actuator + API fake controller |
| 초기화/모드 | API + simulation |
| model joint/axis | kinematics + tripod-gait/scone-gait + reference motion |
| terrain | terrain + simulation |
| arc-wheel/계단 controller | stair geometry + stair climber + simulation |
| reward/observation | remote-watch reward tests + environment check |
| walk_v2 PPO distribution/randomization/evaluation | test_walk_v2 + 64-step smoke train |
| checkpoint/remote command | remote-watch + RL inquiry |
| joystick | API joystick + RL joystick |

실제 serial이나 SSH를 호출하는 검증은 unit test와 분리하고, 명시적으로 선택한 장치/host에서만 한다.

## 10. 문서와 코드 변경 체크리스트

- 새로운 파일을 추가하면 [파일 지도](05-file-and-folder-map.md)를 갱신한다.
- 상수·데이터 클래스·상태 필드를 추가하면 [변수 사전](variables/README.md)을 갱신한다.
- 관측 차원을 바꾸면 shape, 순서, compatibility policy, 테스트, checkpoint 안내를 모두 갱신한다.
- reward를 바꾸면 [보상 가이드](06-reward-function-guide.md)의 수식·기본값·회귀 테스트를 갱신한다.
- model motor 사양을 바꾸면 XML과 `src/simulation/core/pid.py`를 함께 바꾼다.
- profile/stance를 바꾸면 hardware profile, simulation seed, RL stance의 의도적 차이를 기록한다.
- 논문 숫자는 원 로그/영상/설정과 연결된 evidence가 있을 때만 확정한다.

## 11. 현재 운영상 주의사항

- `requirements.txt`는 CLI·Dynamixel·MuJoCo·RL을 통합한다. 새 장치에서는 설치 뒤 대표 ID 1/7/13 ping과 MuJoCo import를 각각 확인한다.
- reward/heading 비교 전에 `SconeWalkEnv.step()`의 heading target 이중 적분을 확인한다.
- `runs/remote_watch/scone_walk_260000_steps.zip.part`는 미완성 파일이므로 policy로 열지 않는다.
- `archive/ICRA`의 결과 표는 아직 실험 증거로 채워지지 않았다.

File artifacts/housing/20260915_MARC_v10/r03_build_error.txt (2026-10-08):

Traceback (most recent call last):
  File "<string>", line 93, in <module>
  File "<string>", line 26, in run
  File "<string>", line 11, in sculpt
  File "/Users/hayward_kim/Library/Application Support/Autodesk/webdeploy/production/127ae56f1790f40cf393bcc73875a1a281e20234/Autodesk Fusion.app/Contents/Api/Python/packages/adsk/fusion.py", line 68099, in add
    return _fusion.ShellFeatures_add(self, input)
           ~~~~~~~~~~~~~~~~~~~~~~~~~^^^^^^^^^^^^^
RuntimeError: 3 : 쉘1 / 계산 실패 // ASM_LOP_TWK_NO_VERT -   작업에서 올바른 결과를 작성할 수 없습니다.
    값을 조정하거나 입력을 변경해 보십시오.

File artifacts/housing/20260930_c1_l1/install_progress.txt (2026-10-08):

C1 applied. Comparing all protected geometry and poses.

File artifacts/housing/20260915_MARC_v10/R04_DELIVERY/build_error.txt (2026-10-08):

Traceback (most recent call last):
  File "<string>", line 78, in <module>
  File "<string>", line 35, in run
  File "<string>", line 15, in intersect
  File "<string>", line 11, in boolean
  File "/Users/hayward_kim/Library/Application Support/Autodesk/webdeploy/production/127ae56f1790f40cf393bcc73875a1a281e20234/Autodesk Fusion.app/Contents/Api/Python/packages/adsk/fusion.py", line 75852, in booleanOperation
    return _fusion.TemporaryBRepManager_booleanOperation(self, targetBody, toolBody, booleanType)
           ~~~~~~~~~~~~~~~~~~~~~~~~~~~~~~~~~~~~~~~~~~~~~^^^^^^^^^^^^^^^^^^^^^^^^^^^^^^^^^^^^^^^^^
RuntimeError: 3 : ASM_EDGECOIN_PROBLEM -   형상을 결합하는 중에 문제가 발생했습니다.
    접합/절단/교차를 시도하는 경우 본체에 명확하게 겹치는 부분이 있는지 확인하십시오(면과 모서리가 거의 일치하는 위치에서 문제가 발생할 수 있음).

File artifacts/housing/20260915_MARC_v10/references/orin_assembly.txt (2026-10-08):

nvPLOT 142-13768-1000-A04 21 Feb 2023 : Assembly TOP

                                                                                                                                                                                                                                                                                                                                 J14                                                                                                                                                                                                                                                           J17
                                                                                                                                                                                                                                                                                                                                                                                                                                                                                                                                                                                                                                                                               2DID
                                                                                                                                                                                                                                                                                                                                                                                                                                                                                                                                                                                                                                                                                                                                                                                R543
                                                                                                                                                                                                                                                                                                                                                                                                                                                                                                                                                                                                                                                                                                                                                                R119     R122
                                                                                                                      R95     R453         R454     R12

                                                                    R181
                                                                           C168
                                                                                         Q25                                                                                                                                                                                                                                                                                                                                                                                                                                                                                                                                                                                                                                                             C429          U15      C430
                                                                                                                                                                                                                                                                                                                                                                                                                                                                                                                                                                                                                                                                                                                                                                                                                     J13
                                                                                                                                                                                                                                                                                                                                                                                                                                                                                                 R136
                           D35

                                                                    R182
                                                                                                                             U11                                                                                                                                                                                                                                                                                                                                                                             Q21

                                                                                                                                                                                                                                                                                                                                                                                                                                                                                                                        R133                                                                                                                                                                                                                                                                                                                                  C132
                                                                                                                                                                                                                                                                                                                                                                                                                                                                                                          R134
                                                                                                                                                                           D3                                     C133                                                                                                                    R223                  D81                                D48                        D49           R121
                                                                                                                                                                                           D2                                          D1                                                                                                                                                                                                                                            R135                                       R1
                                                                                                                                                                                                                                                                                                                                                                                                                                                                                                                         R2
                                            R426                                                                       R450    R451         R452
                                                                                                                                                                                                                                                                                                         R201      C170
                                                                                                                                                        R11                                                                                                                                                                                                                                                                                                                                                                                                                                                                                                                                                                                                                                                                                                   R124
                                                                                                                                                                           R9                                     R203                                                                                                                                                                                                                                                                                                                     R7
                                     C106
                                                                                   R260
                                                                                                                                                                                                                                                                                                                                                                                                                                                    R120
                                                                                                                                                                                                                                                                                                                                                                                                                         U16
                                                                                                                                                                                                                                                                                                                                               R127
                                                                                                      R261                                                                                                                                                                                                                                                    R130     R129    R131                                                                                                                                       Q1                                                                                                                                                                                                                                                                                                                     Q20
                                                            U57                   C203
                                                                                                                                                                    R512     R513   R514   C392
                                                                                                                                                                                                                                                                                                                                               R128
                                                                                                                                                                                                                                                                                                                                                                                               C130      R125                                                                                                                                                                                                                                                                                R425                                                                                                                                                             R123

                                                                                                                                                                                                                                                                                                                                                                                                                                                                                                                                                                                                                                                                 D63
                                                                                                                                                                                                                    U23                                                                                                                                                                                                                                                                                                                                                                                                                           R141
                                                      D34                                                                                                R497                                                                                                                                                                                                                                                                              C129
                                                                                                                                                                                                                                                                                                                                                                               R132                                                                                                                                                                                                                                                                                                                                                                                                    R422   C334

                                                                                                                                                                                                                                                                                                              U28
                                                                                                                                                                                                                                                                                                                                                                                                                                                                                                                                        Q48                                                                     R479
                                                                                                                                                                                                                                                                                                                                                                                                                                                                                                                                                                                                                                  R140                                                        C342                 R412
                                                                                                                                                                                                                                                                                                                                                                                                                                                                                                                                                                                                                                                                                                                                                                                                                                                       C125

                                                                                                                                                                                U56
                                                      D33                                 C204
                                                                                                                                                                                                                                                                                                                                                        U17
                                                                                                                                                                                                                                                                                                                                                                                                                                                                                                                                                                                 Q56                            R231
                                                                                                                                                                                                                                                                                                                                                                                                                                                                                                                                                                                                                                         C135                                                 R424
                                                                                                                                                                                                         R518                                                                                                                                                                  C134                                                                                                                                                                                                                             R523
                                                                                                                                                                                                                                                                                                                                                                                                                                                                                                                                                                                                                                                                       R183
                                                                                                                                                                                                                                                                                                                                                                                                                                                                                                                                                                                                                                                                                                                                 C327
                                                      D32                                                                                                                                                                                                                                                                                                                                                                                                                                                                                                                                                                                                              R184
                                                                                                                                                                                                                                                                                                                                                                                                                                                                                                                                                          R386     R384
                                                            D31                                                                                                                                                                                                                                                                                                                                                                                                                                                                                                                                R524
                                                                                                                                                                                                                                                                                                                                                                                                                                                                                                                                                                                                                                                                                      R423   C338      C332
                                                                                                       C166                                                                                                                                                                                                                                                                                                                                                                                                                     C404                                                                                R138

                                                                                                                                                                                                                                                                                                                                                                                                                                                                                                                                                                                                                                         U18
                                                                                                                                                                                                                                                                                                                                                                              R126                                                                                                                                              C304
                                                                                                                                                                                                                                                                                                                                                                                                                                                                                                                                                                                                          R542
                                                                                                                                                                                                                                                                                                                                                                                                                                                                                                                                                                                                                                                                       R227

                                                                                                                                                                                                                                                                                                                                                                                                                                                                                                                                                                                                                                                                                                                                                                                                                                      U13
                                                                                                                                                                                                                                                                                                                                                                                                                                                                                                                                                                                           C374
                                                                                                                                                                                                                                                                                                                                                                                                                                                                                                                                                                                                                    R525

              J20
                                                                                                                                                                                                                                                                                                  R200     R199
                                                                                                                                                                                                                                                                                                                                                                                                                                                                                                                                                                                                                                                                       R228    R166
                                                                                                                                                                             C49                                            C60        C62
                                                            D30                                                                                                                                              C5     C4                                                                                                                                                        D76
                                                      D29                                              C167                                                                                                                                                                                                                                                                                                                                C375
                                                                                                                                                                                                                                                                                                                                                                                                                                                                                                                                                                                                                   R137
                                                                                                                                                                                                                                                                                                                                                                                                                                                                                                                                                                                 Q46
                                                                                                                                                                                                                                                                                                  R36      R38
                                                                                                                                                                                                                                                                                                                                                                                                                              U53
                                                                                                                                                                                                                                                                                                                                                                                                                                                                                                                                        Q50                                                                                                                                U22
                                                                                                                                                                                                                                                                                                                                                                              D75                                                                                                                                                                                                                                  R139
                                                      D28    R480                                      C358                                C40                                                                                                                                                                                                                                                                                                                                                                                                                                                                     R198       C169

                                                                                                                                                                                                                                                                                                                                                                                                                                                                                                                                                                                                                                                     D62
                                                             R496
                                                      D27
                                                                                                                                                                                                                                                                                                                                                                                                                                                                                                                                                                                                                                                                        R170
                                                                                                                                                                                                                                                                                                                                                                                                                                                                                                                                                                                                                             D66
                                                                                                                                                                                                                                                                                                                                                                                                                                                                                                                                                                                                                                                                                                                                                                                                              C407
                                                                                                                                                                                                                                                                                                                                                                                                                                                                                                                                                                                   C305

                                                      D26                                                                                                                                                                                                                                                                                                                                                                                                            R102                                                                                                                                          R195                                                                                                                                                                                                      C324
                                                            D25
                                                                                                                                                                                                                                                                                                                                                                                                                                                                                                                                                                                                                                           R142
                                                                                                                               C41

                                                                                                                                                                                                                                                                                                                                                                                                                       R104
                                                                                                                                                                                                                                                                                                                                                                                                                                                                     Q17
                                                                                                                                                                                                                                                                                                                                                                                                                                                                                      R99          R100
                                                                                                                                                                                                                                                                                                                                                                                                                                                                                                                                        Q49                                                                                                                                                                                                                                                                                                  R3           D77

                                                                                                                                                                                                             U7
                                                                                                                                                                                                                                                                                                            C47
                                                                                                                                                                                                                                                                                                                                                                                                                                                                                                                                                                                                                                                         Q28
                                                                                                                                                                                                                                                                                                                                                                                                                                                                                                                                                                                                                                  Q29
                                                            D24

                                                                                                                                                                                                                                                                                                                                                                                                                                                                                                                                                                                                         C414
                                                                                                                                                                                                                                                                                                                                                                                                                                                                                                                                                                                                                                                                                                                                                                                                                             C323
                                    C396 C253 C395                                                                                                                                                                                                                                                                                                                                                                                                                   Q18
                                                                                                                                                                                                                                                                                                                                                                                                                                                                                                                                                                                                                   R197
                                                                                                                                                                                                                                                                                                                                                                                                                                                                                   R103
                                                                                                                                                                                                                                                                                                                                                                                                                                                                                                                                                                           Q57                                                             R226             R196
                                                                                                                                                                                                                                                                                                                                                                                                                                                                                                                                                                                                                                                                                                                                                                                                                                             R4           D78

                                                                                                                                                                                                                                                                                                                                                                                                                                                                                                                                                          R385                                            R526
                                    C398 C255 C397                                                                                                                                                                                                                                                                                                                                                                                                                                                                               C403                                                                                                                                                                                                                                                                                        C405
                                                                                                                               C42

                                                                                                                                                                                                                                                                                                                                                                                                                                                                                                                                                                                                                   C427
                                                                                                                                                                                                                                                                                                                                                                                                                                                                                                                                 C303
                                                                                                                              R174
                                    R467 R466 R465
                                                                                                                                                                                                                                                                                                                                                                                                                                                                                                                 R106    R107                                                                      R516

                                    R473 R472 R471
                                                                                                                                                                                                                                                                                                    C46                                                                                                                U58                                                                                                                                                       R383              R515
                                                                                                                                                                                                                                                                                                                                                                                                                                                                                                                                                                                                                                                                                                                                                  C307
                                                                                                                                                                                                                                                                                                                                                                                                                                                                                                                                                                                                                                                                                                                                                                R403

                                                                                                                                                                                                                                                                                                                                                                                                                                                                                                                                                                                                                                                                                                                                                                C314
                                                                                                                                                                                                                                                                                                                                                                                                                                                                                                                                                                                                                                                         C408
                                                                                                                                                  C56
                                                                                                                                                                                                                                                                                                                                                                                                                                                                                                                                        Q47                                                                                   U5
                                                                                                                                                                                                                                                                                                                                                                                                                                                                                                                                                                                                                                                                                                                                                                                                                                      U12
                                                                                                                              C58
                    C391     R519
                                                                                                                                                                                                                                                                                                                                                                                                                                                                                                                                                                          R381          R380
                                                                                                                                                                                                                                                                                                                                                                                                                                                                                                                                                                                                   C411
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

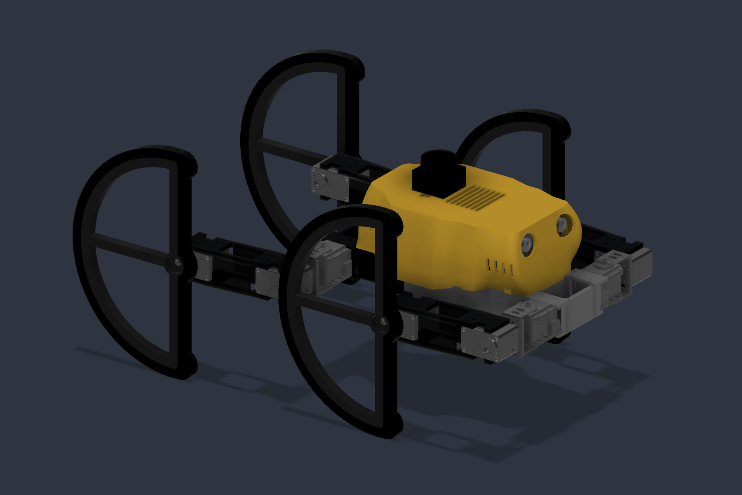
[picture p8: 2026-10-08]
artifacts/housing/20260915_MARC_v10/r03_assembly.png

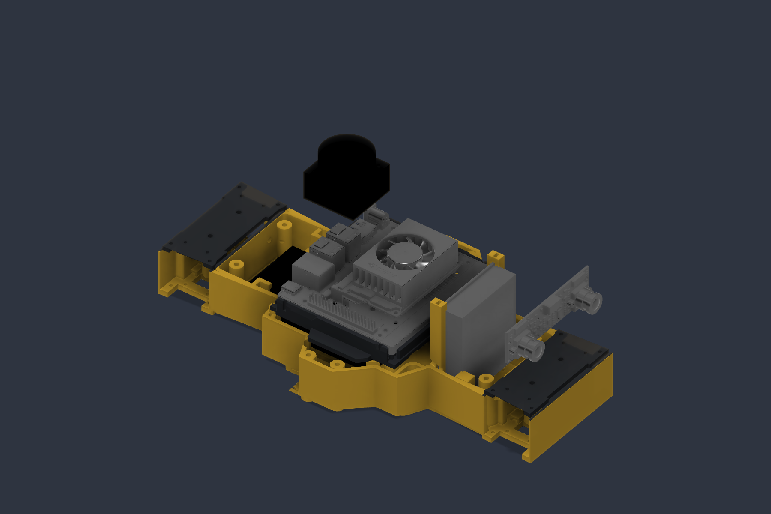
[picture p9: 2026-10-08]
artifacts/housing/20260915_MARC_v10/R09_DELIVERY/PRINT_PACKAGE/internals.png

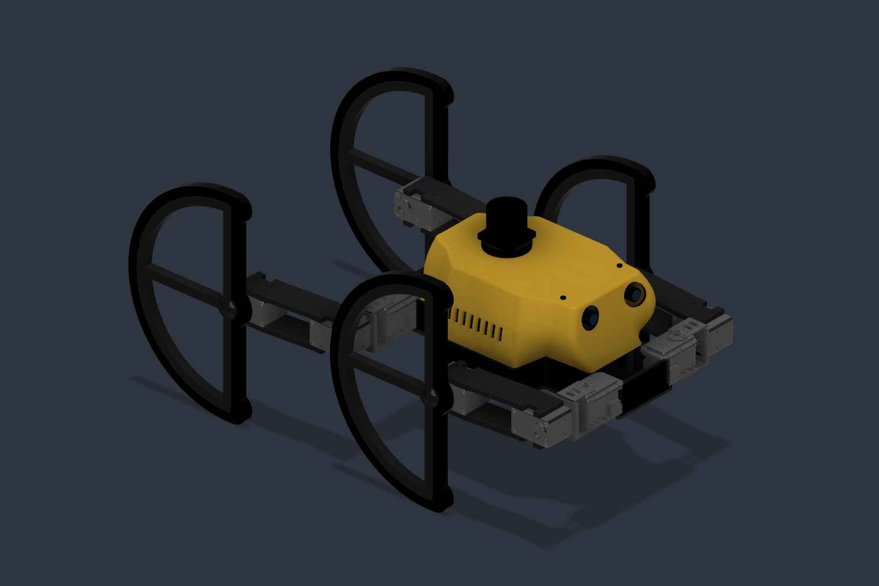
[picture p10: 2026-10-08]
artifacts/housing/20260915_MARC_v10/housing_assembly.png

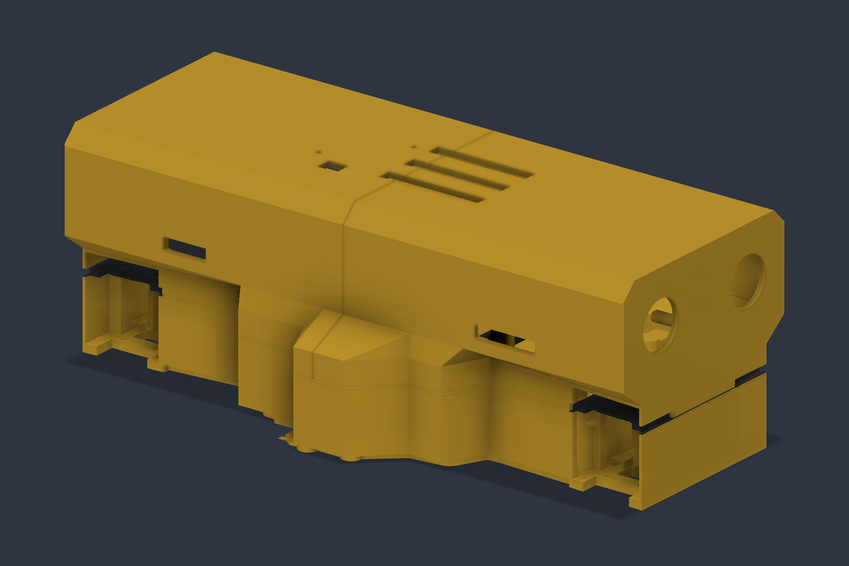
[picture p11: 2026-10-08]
artifacts/housing/20260915_MARC_v10/R09_DELIVERY/PRINT_PACKAGE/housing_detail.png

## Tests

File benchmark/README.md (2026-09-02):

# SCONE simulation benchmarks

This package runs paper-oriented, headless MuJoCo experiments without changing
the physical controller or the existing simulation routes. Every trial creates
a fresh model, data, virtual controller, and robot, then writes one JSON object.

The benchmark is evidence about the current MuJoCo model. It is not a substitute
for repeated physical-robot tests or simulation-to-real calibration.

## Locked ICRA protocol

Use the `icra` suite for publication-facing runs. It is intentionally separate
from the historical A/B/C commands below.

```bash
# Fast end-to-end validation of both contact geometries and all output files.
python -m benchmark icra \
  --profile smoke \
  --suite all \
  --seed 2027 \
  --output-dir benchmark/results/icra/smoke-seed-2027

# Small tuning/debug set. Do not report it as the held-out evaluation.
python -m benchmark icra --profile pilot --suite all --seed 12027

# Locked publication set: 20 paired trials, a nine-command grid and all stairs.
python -m benchmark icra --profile evaluation --suite all --seed 22027
```

The protocol crosses two contact geometries with matched controllers:

| Factor | Levels |
| --- | --- |
| Contact | exported `open-arc`; same-radius/width `closed-wheel` cylinder |
| Flat control | `matched-articulated`; `matched-distal-only`; `matched-coordinated` |
| Stair control | `distal-only`; `full-scone` |

The closed cylinder replaces collision geometry only. The explicit body mass,
inertia, actuator, friction, contact solver parameters, and outer envelope are
preserved. All matched flat controllers use the same `RollGaitConfig`, actuator
limits, 60-degree tripod-B distal phase pose, and gait-phase calibration. For a
given `pair_id`, every geometry/controller condition receives the same sampled
mass, friction, actuator-strength, initial-pose and gait-phase perturbation plus
the same terrain seed.

Each output directory starts with `protocol.json` and refuses to overwrite an
existing manifest. Records include the model-plus-mesh SHA-256, MuJoCo version,
Git revision/dirty flag, solver settings, physics/control time steps, geometry,
pair ID and every sampled perturbation. The suite writes raw JSONL, ordinary
group summaries, and candidate-minus-reference paired-difference CSV files.
Binary outcomes use Wilson intervals; continuous means and paired differences
use deterministic percentile-bootstrap intervals.

`sensitivity` reruns a fixed nominal condition at 1, 2 and 4 ms physics steps.
This checks numerical convergence separately from controller/morphology effects.
The mass/friction/strength ranges are sensitivity ranges, not measured hardware
uncertainty distributions. Before submission they must be replaced or justified
using assembled-mass, motor and TPU/contact identification data.

## Suites

### Flat A/B/C ablation

The main same-model comparison is:

| Name | Proximal stages | Distal C-frames |
| --- | --- | --- |
| `articulated-walk` | alternating-tripod IK | bounded position motion |
| `distal-only-roll` | held at the initialized pose | continuous rotation |
| `full-roll` | SCONE stabilizing gait | continuous rotation plus bounded lower-rate term |

Run one quick comparison:

```bash
python -m benchmark flat \
  --all \
  --command forward \
  --trials 1 \
  --duration 8 \
  --output benchmark/results/flat-nominal.jsonl
```

Run a command grid with ten randomized initial gait phases:

```bash
python -m benchmark flat \
  --all \
  --command idle \
  --command forward \
  --command reverse \
  --command left \
  --command right \
  --command yaw-left \
  --command yaw-right \
  --command forward-turn \
  --trials 10 \
  --duration 8 \
  --output benchmark/results/flat-grid.jsonl
```

`bounded-scone` is available as an engineering comparison, but it is not one of
the paper's primary A/B/C conditions. It is the model-based bounded reference,
not PPO.

These conditions compare the controllers currently implemented in SCONE on the
same MJCF. Their motion profiles and gains are not yet normalized to an equal
actuation budget, so report them as an as-implemented controller ablation. A
paper claim about morphology alone additionally requires a torque-, speed-, and
control-bandwidth-matched ablation.

### Stair A/B/C and geometry sweep

Paper-facing names are mapped onto the existing deterministic stair engine:

| Name | Existing implementation |
| --- | --- |
| `distal-only` | `pure-rolling` |
| `synchronized-open-loop` | fixed 270-degree leading brace and open-loop distal velocity |
| `full-scone` | rise-conditioned partial brace and closed-loop shared phase |

Run all three preset heights:

```bash
python -m benchmark stairs \
  --all \
  --trials 1 \
  --output benchmark/results/stairs-nominal.jsonl
```

Run a custom riser/tread Cartesian sweep:

```bash
python -m benchmark stairs \
  --all \
  --riser-mm 80 --riser-mm 100 --riser-mm 120 --riser-mm 150 --riser-mm 200 \
  --tread-mm 200 --tread-mm 270 --tread-mm 350 \
  --trials 1 \
  --output benchmark/results/stairs-geometry.jsonl
```

Repeated nominal stair runs are exactly deterministic. Use `--randomize` to
sample mass, friction, and actuator-strength scales when estimating a simulated
success rate:

```bash
python -m benchmark stairs --all --preset stairs-3 --trials 20 --randomize
```

### Robustness Monte Carlo

The robustness suite samples mass, sliding friction, actuator strength, initial
position, yaw, gait phase, and procedural terrain seed:

```bash
python -m benchmark robustness \
  --all \
  --terrain uneven \
  --trials 100 \
  --output benchmark/results/robustness.jsonl
```

The default ranges are mass `0.9..1.1`, friction `0.4..1.2`, and actuator
strength `0.85..1.15` relative to the current MJCF.

### Mode transitions

This suite records the whole neutralization, mode change, pose acquisition, and
recovery window. For `roll-to-walk`, `mode_switch_duration_s` ends only after all
18 joints reacquire the Standard walk pose within 96 raw units.

```bash
python -m benchmark transitions \
  --all \
  --trials 20 \
  --output benchmark/results/transitions.jsonl
```

### Statistical summary

Create a CSV grouped by benchmark, controller, and command. Continuous metrics
include mean, sample standard deviation, and deterministic percentile-bootstrap
95% intervals. Binary success uses a Wilson 95% interval.

```bash
python -m benchmark report \
  benchmark/results/flat-grid.jsonl \
  --output benchmark/results/flat-grid-summary.csv
```

### Compact simulation media

Capture the paper-facing flat A/B/C, 200 mm stair A/B/C, Walk/Roll
transitions, and one reproducible uneven-terrain sensitivity example. Use
`mjpython` on macOS so MuJoCo owns the graphics context on the main thread.

```bash
mjpython -m benchmark capture --suite all
```

The default output is `archive/simulation_media/`: 640x360, 15 fps H.264 MP4
at CRF 34 plus one progressive JPEG per scene. Frames are streamed directly to
FFmpeg, so no uncompressed source video is written. `manifest.json` records the
scene parameters, outcomes, frame counts, durations, and file sizes.

## Recorded flat/transition metrics

- body-frame displacement, average `vx/vy`, yaw change and tracking RMSE;
- root-height variation, roll/pitch RMS and extrema, minimum upright value;
- absolute mechanical work `integral(abs(tau*qdot)) dt` and mechanical COT;
- estimated absolute terminal electrical energy `integral(abs(V*I)) dt`;
- peak actuator torque, estimated motor current, and contact force;
- tire-ground tangential slip distance and mean loaded contact count;
- non-tire ground-collision steps;
- IK failures, stride clipping, and minimum IK backoff scale;
- Git revision and dirty-worktree flag.

Electrical energy is reconstructed from the simulated dcmotor terminal voltage,
back-EMF, and resistance. It is an estimate, not a measured battery-energy
result. Stair `work_to_top_j` is also simulated absolute mechanical work.
The loaded contact count is the number of distinct tire bodies carrying at
least 1 N normal contact force, not MuJoCo's raw number of contact points.

## Experimental rules

1. Freeze a Git revision before producing paper numbers.
2. Do not combine results from different MJCF/controller revisions.
3. Tune on one set of terrain seeds and report a disjoint evaluation set.
4. Do not treat identical deterministic repeats as independent trials.
5. Report traversal-only and end-to-end stair timing separately when preparation
   time is part of the research question.
6. Never mix legacy A/B/C records with `icra` matched-controller records.
7. Run the pilot and held-out evaluation with different pre-registered seeds;
   do not retune after inspecting evaluation outcomes.
8. Treat the open-vs-closed result as a frozen-controller morphology effect.
   If either geometry is retuned, report that as a separate tuned comparison.
9. The current MJCF has no mechanical joint limits and its TPU/friction model is
   not identified from hardware; disclose this until calibration is complete.

Generated result files under `benchmark/results/` are ignored by Git.

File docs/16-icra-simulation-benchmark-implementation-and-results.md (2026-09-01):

# ICRA 시뮬레이션 벤치마크 구현과 실행 기록

## 1. 문서 목적

이 문서는 2026-09-01에 ICRA 제출용 실험 기반을 만들기 위해 수행한 SCONE
시뮬레이션 벤치마크 작업을 정리한다. 구현한 코드, 실험 조건, 실제 실행 명령,
측정 결과, 검증 상태와 아직 논문 근거로 사용할 수 없는 부분을 한곳에 기록한다.

이번 작업의 목표는 다음 질문을 재현 가능한 코드로 검사하는 것이었다.

1. 같은 SCONE MuJoCo 모델에서 관절 보행, 말단만 회전, 전체 SCONE 회전은
   전진 속도와 안정성·에너지·미끄러짐에서 어떻게 다른가?
2. 계단에서 말단 회전만 사용하거나 고정 open-loop 동작을 사용하는 것보다
   SCONE의 능동 관절과 부채꼴 말단을 함께 사용하는 방식이 더 높은 형상을
   통과하는가?
3. 질량·마찰·액추에이터 출력과 초기 조건이 달라져도 결과가 유지되는가?
4. 보행과 주행 사이 모드 전환은 어느 정도 시간이 걸리고 자세를 유지하는가?

이 벤치마크는 현재 MuJoCo 모델과 현재 controller 구현에 대한 증거다. 실물
SCONE의 성능을 자동으로 입증하지 않으며, 시뮬레이션-실물 보정과 반복 실험을
대체하지 않는다.

## 2. 추가한 파일

| 경로 | 역할 |
|---|---|
| [`benchmark/__main__.py`](../benchmark/__main__.py) | `python -m benchmark`의 통합 subcommand 진입점 |
| [`benchmark/common.py`](../benchmark/common.py) | fresh MuJoCo trial, 모델 perturbation, 공통 지표, JSONL/CSV 출력 |
| [`benchmark/controllers.py`](../benchmark/controllers.py) | 평지 A/B/C controller adapter |
| [`benchmark/flat.py`](../benchmark/flat.py) | 평지 명령 추종 및 A/B/C 비교 |
| [`benchmark/robustness.py`](../benchmark/robustness.py) | 질량·마찰·출력·초기 자세·지형 seed Monte Carlo |
| [`benchmark/stairs.py`](../benchmark/stairs.py) | 계단 A/B/C와 riser/tread Cartesian sweep |
| [`benchmark/transitions.py`](../benchmark/transitions.py) | Walk→Roll, Roll→Walk 전환 측정 |
| [`benchmark/report.py`](../benchmark/report.py) | JSONL/CSV 집계, 평균·표준편차·95% CI 생성 |
| [`benchmark/README.md`](../benchmark/README.md) | 각 suite의 실행법과 해석 규칙 |
| [`benchmark/results/.gitignore`](../benchmark/results/.gitignore) | 생성된 실험 결과를 Git 소스와 분리 |
| [`tests/test_benchmark.py`](../tests/test_benchmark.py) | 입력 검증, 짧은 동역학 실행, 통계·파일 출력 회귀 테스트 |

기존 하드웨어 controller와 공용 locomotion 파일은 이 작업에서 변경하지 않았다.
벤치마크는 기존 구현을 adapter로 호출하므로 실물 제어 경로에 별도 동작을
추가하지 않는다.

## 3. 공통 실행 구조

평지·강건성·전환 trial은 다음 순서로 실행된다.

```text
MJCF + terrain 로드
  → 질량/마찰/actuator strength perturbation
  → 새 MjData·MuJoCoController·SCONE 생성
  → 기존 robot.initialize() 실행
  → controller별 준비 자세
  → 50 Hz 명령, MuJoCo physics step 반복
  → 상태·접촉·토크·에너지 누적
  → JSONL 한 줄 저장
```

각 trial은 모델, `MjData`, controller와 robot을 새로 생성한다. 이전 trial의
적분기·관절 상태·접촉 상태가 다음 trial에 남지 않는다. 결과에는 Git revision과
dirty-worktree 여부도 함께 저장한다.

## 4. 실험 조건

### 4.1 평지 A/B/C

| 논문용 이름 | 상·중단 관절 | 하단 부채꼴 말단 |
|---|---|---|
| `articulated-walk` | 기존 alternating-tripod IK 보행 | bounded position motion |
| `distal-only-roll` | 초기 목표 자세에 고정 | velocity mode 연속 회전 |
| `full-roll` | 현재 SCONE stabilizing gait | 연속 회전과 phase stagger |

명목 실행은 평지에서 `vx=0.18 m/s`, 1초 settling, 6초 측정, gait phase 0으로
진행했다. `completed=True`는 목표 속도 달성을 의미하지 않는다. 비정상 수치가
발생하지 않고 root tilt가 60° 한계를 넘지 않은 채 측정 창을 완료했다는 뜻이다.

세 조건은 같은 MJCF에서 현재 구현된 controller를 비교하지만, controller별
motion profile·gain·bandwidth가 완전히 동일한 구동 예산으로 정규화된 것은
아니다. 따라서 현재 결과는 **as-implemented controller ablation**이다. 구조
자체의 우월성을 주장하려면 토크·회전속도·제어주기·명령 saturation을 맞춘
추가 ablation이 필요하다.

### 4.2 계단 A/B/C

| 논문용 이름 | 기존 계단 구현 | 의미 |
|---|---|---|
| `distal-only` | `pure-rolling` | 상·중단의 능동 계단 자세 없이 말단 회전 |
| `synchronized-open-loop` | 동명의 기존 전략 | 앞 1단 270° brace와 고정 distal velocity |
| `full-scone` | `adaptive` | riser별 partial brace와 closed-loop shared phase |

계단 성공은 기존 `stair_benchmark`의 `top_reached` 판정으로 결정한다. preset뿐
아니라 사용자가 지정한 riser와 tread 조합을 임시 `StairProfile`로 만들어
Cartesian sweep할 수 있다. 임시 profile은 trial 종료 후 원래 preset으로
복구한다.

### 4.3 강건성

기본 Monte Carlo 범위는 다음과 같다.

- 전체 body mass/inertia: 현재 모델의 `0.9..1.1`배
- sliding friction: `0.4..1.2`배
- actuator gain과 force range: `0.85..1.15`배
- 초기 x/y: 각각 `±30 mm`
- 초기 yaw: `±5°`
- gait phase: `0..1`
- procedural terrain seed: trial마다 분리

현재 perturbation은 모든 body·actuator에 같은 scale을 적용한다. 부품별 질량
오차, 배터리 위치 오차, 타이어 이방성·속도 의존 마찰은 아직 포함하지 않는다.

### 4.4 모드 전환

- `walk-to-roll`: 보행 → neutralization → Roll 준비 자세 → velocity mode → 회복
- `roll-to-walk`: Roll → neutralization → position mode → Standard 18관절 목표
  재획득 → 보행 회복

`roll-to-walk`의 `mode_switch_duration_s`는 모든 18개 관절이 Standard 목표의
96 raw 이내에 들어올 때까지 포함한다. 전체 recorder는 전환 직전 neutralization과
전환 뒤 recovery도 측정한다.

## 5. 기록하는 지표와 계산법

### 이동과 명령 추종

- 시작 body frame 기준 `x/y/z` 변위와 평균 `vx/vy`
- 누적 yaw와 평균 yaw rate
- 매 physics step의 body velocity 및 yaw-rate RMSE
- 횡방향 drift와 명령 반대 방향으로 이동한 거리

### 자세 안정성

- root 높이의 최저·최고·RMS 변화
- roll/pitch RMS와 최대 절댓값
- body z축과 world z축 내적으로 계산한 `minimum_upright`
- non-finite state 또는 최대 tilt 초과 termination

### 구동과 에너지

- 절대 기계일:

  ```text
  W_mech = integral(sum(abs(tau_i * qdot_i))) dt
  ```

- 기계적 Cost of Transport:

  ```text
  COT = W_mech / (total_mass * g * horizontal_distance)
  ```

- motor resistance·back-EMF와 simulation terminal voltage로 복원한 절대 전기
  에너지 추정치
- peak actuator torque와 추정 motor current

전기 에너지는 배터리에서 측정한 값이 아니다. 회생과 driver 손실을 실제 전원계와
동일하게 모델링한 결과도 아니므로 논문에서는 반드시 **estimated electrical
energy**로 표기한다.

### 접촉과 제어 품질

- peak contact force
- contact-point Jacobian으로 계산한 타이어-지면 접선 slip distance
- 1 N 이상의 normal force를 받는 서로 다른 타이어 body 수의 시간 평균
- 타이어 외 부품이 지면과 충돌한 physics step 수
- IK 실패 frame, 평균 stride clipping, 최소 IK backoff scale

하나의 타이어에서 MuJoCo contact point가 여러 개 생겨도 지지 다리는 하나로
계산한다. 다만 slip은 접촉점 속도의 평균을 적분하므로 실물 타이어 변형량을
직접 뜻하지 않는다.

## 6. 실제 실행 명령

### 코드와 단위 테스트

```bash
python -m compileall -q benchmark tests/test_benchmark.py
python -m unittest tests.test_benchmark -v
git diff --check -- benchmark tests/test_benchmark.py
```

### 평지 명목 A/B/C

```bash
python -m benchmark flat \
  --all \
  --command forward \
  --trials 1 \
  --duration 6 \
  --settle 1 \
  --no-random-phase \
  --output benchmark/results/flat-nominal.jsonl
```

### 세 preset의 계단 A/B/C

```bash
python -m benchmark stairs \
  --all \
  --trials 1 \
  --output benchmark/results/stairs-nominal.jsonl
```

### 모드 전환

```bash
python -m benchmark transitions \
  --all \
  --trials 1 \
  --output benchmark/results/transitions-nominal.jsonl
```

### 짧은 강건성 실행

```bash
python -m benchmark robustness \
  --all \
  --terrain uneven \
  --trials 3 \
  --duration 2 \
  --output benchmark/results/robustness-smoke.jsonl
```

### 통계 리포트

```bash
python -m benchmark report benchmark/results/flat-nominal.jsonl \
  --output benchmark/results/flat-nominal-summary.csv

python -m benchmark report benchmark/results/stairs-nominal.jsonl \
  --output benchmark/results/stairs-nominal-summary.csv

python -m benchmark report benchmark/results/robustness-smoke.jsonl \
  --output benchmark/results/robustness-smoke-summary.csv

python -m benchmark report benchmark/results/transitions-nominal.jsonl \
  --output benchmark/results/transitions-nominal-summary.csv
```

### 전체 회귀 테스트

```bash
python -m unittest discover -s tests -v
```

## 7. 실제 결과

### 7.1 평지 명목 실행

모든 조건은 6초 측정 창을 완료했다.

| Controller | 평균 vx (m/s) | 속도 RMSE (m/s) | 기계일 (J) | 추정 전기에너지 (J) | COT | slip (m) | 평균 지지 다리 | minimum upright |
|---|---:|---:|---:|---:|---:|---:|---:|---:|
| `articulated-walk` | 0.1171 | 0.0971 | 18.95 | 27.46 | 0.661 | 0.212 | 3.668 | 0.9999 |
| `distal-only-roll` | 0.0897 | 0.2679 | 57.01 | 171.57 | 2.576 | 1.603 | 2.797 | 0.9759 |
| `full-roll` | 0.2001 | 0.2529 | 60.24 | 139.76 | 1.227 | 1.323 | 3.114 | 0.9769 |

현재 결과에서는 `full-roll`이 가장 빨랐고 `distal-only-roll`보다 slip과 추정
전기에너지가 작았다. 그러나 `articulated-walk`보다 기계일과 slip이 크다.
또한 목표 `0.18 m/s`를 넘는 controller의 순간 진동 때문에 RMSE가 커질 수
있으므로 평균 속도 하나만으로 추종 성능을 판단하면 안 된다.

`distal-only-roll`과 `full-roll`의 stride clipping 약 0.993은 두 adapter가
공유하는 planning 진단값이다. 말단만 회전하는 조건에서 실제 상·중단 관절의
clipping으로 그대로 해석하지 않는다.

- 원본: [`benchmark/results/flat-nominal.jsonl`](../benchmark/results/flat-nominal.jsonl)
- 요약: [`benchmark/results/flat-nominal-summary.csv`](../benchmark/results/flat-nominal-summary.csv)

### 7.2 계단 명목 실행

| Riser / tread | `distal-only` | `synchronized-open-loop` | `full-scone` |
|---|---:|---:|---:|
| 100 / 240 mm | 성공, 4.886초 | 성공, 3.818초 | 성공, 2.646초 |
| 150 / 200 mm | 성공, 14.960초 | 성공, 5.546초 | 성공, 6.736초 |
| 200 / 350 mm | 실패 | 실패 | 성공, 5.964초 |

`full-scone`의 성공 trial 기계일은 각 형상에서 45.50 J, 95.48 J, 88.18 J였다.
200 mm 조건에서만 `full-scone`이 성공한 결과는 논문 가설을 지지할 가능성이
있지만 현재는 결정론적 simulation 1회다. seed·마찰·출력 perturbation 반복과
실물 계단 교차 검증 전에는 일반적인 등반 우월성으로 주장하지 않는다.

- 원본: [`benchmark/results/stairs-nominal.jsonl`](../benchmark/results/stairs-nominal.jsonl)
- 요약: [`benchmark/results/stairs-nominal-summary.csv`](../benchmark/results/stairs-nominal-summary.csv)

### 7.3 강건성 스모크 실행

불규칙 지형, 각 controller 3회, trial당 2초 결과다.

| Controller | 완료 | 평균 vx (m/s) | vx 범위 (m/s) | 평균 기계일 (J) | 최저 upright |
|---|---:|---:|---:|---:|---:|
| `articulated-walk` | 3/3 | 0.0768 | 0.0732–0.0815 | 6.98 | 0.9999 |
| `distal-only-roll` | 3/3 | 0.1025 | 0.0668–0.1380 | 12.89 | 0.9922 |
| `full-roll` | 3/3 | 0.2009 | 0.1893–0.2143 | 22.16 | 0.9924 |

세 번의 짧은 실행은 Monte Carlo 파이프라인과 seed 분리를 확인한 smoke test다.
성공률이나 신뢰구간을 논문에 쓰기에는 표본과 시간이 부족하다.

- 원본: [`benchmark/results/robustness-smoke.jsonl`](../benchmark/results/robustness-smoke.jsonl)
- 요약: [`benchmark/results/robustness-smoke-summary.csv`](../benchmark/results/robustness-smoke-summary.csv)

### 7.4 모드 전환 실행

| 전환 | 전환 시간 (s) | 전체 기록 시간 (s) | 전체 평균 vx (m/s) | minimum upright | 완료 |
|---|---:|---:|---:|---:|---:|
| Walk→Roll | 0.342 | 2.542 | 0.1451 | 0.9907 | 성공 |
| Roll→Walk | 0.660 | 2.860 | 0.0138 | 0.9904 | 성공 |

Roll→Walk 평균 속도가 낮은 것은 18관절 pose 재획득 시간이 전체 기록 창에
포함되기 때문이다. 전환 1회 결과이므로 평균 전환 시간이나 신뢰구간으로
보고하지 않는다.

- 원본: [`benchmark/results/transitions-nominal.jsonl`](../benchmark/results/transitions-nominal.jsonl)
- 요약: [`benchmark/results/transitions-nominal-summary.csv`](../benchmark/results/transitions-nominal-summary.csv)

### 7.5 추가 스모크 확인

- controller별 1초 평지 A/B/C 실행
- 120 mm riser / 300 mm tread custom 계단에서 `full-scone` 성공
- 짧은 Walk↔Roll 양방향 전환
- 단일 무작위 강건성 trial
- `python -m benchmark --help` subcommand 노출

이 파일들은 개발 중 pipeline 확인용이며 `benchmark/results/` 아래에서 Git에
추적하지 않는다.

### 7.6 저용량 시뮬레이션 영상과 사진

평지 A/B/C 3개, 200 mm 계단 A/B/C 3개, Walk↔Roll 전환 2개, 고정
perturbation 불규칙 지형 A/B/C 3개를 동일한 캡처 설정으로 저장한다.

```bash
mjpython -m benchmark capture --suite all
```

기본값은 640×360, 15 fps, H.264 CRF 34와 JPEG quality 72다. frame은 FFmpeg
stdin으로 직접 전달하므로 무압축 중간 영상은 남지 않는다. 파일과 장면별 결과는
[`archive/simulation_media/README.md`](../archive/simulation_media/README.md)와
[`manifest.json`](../archive/simulation_media/manifest.json)에 기록한다. 영상은
화면상 동작 확인 자료이며 정량 성능값은 원본 JSONL을 우선한다.

## 8. 통계 처리

`benchmark report`는 기본적으로 `benchmark`, `controller`, `command_name`으로
그룹화한다.

- 이진 성공률: Wilson 95% confidence interval
- 연속값: 표본 평균, sample standard deviation, normal-approximation 95% CI
- `N=1`: 평균은 기록하지만 연속값 CI는 `NaN`
- 실패 trial에서 존재하지 않는 `time_to_top_s` 등은 해당 연속 지표의 N에서 제외

결정론적 nominal trial을 같은 조건으로 여러 번 복제해도 독립 표본이 아니다.
성공률을 추정하려면 seed나 식별된 물리 파라미터를 사전에 정한 분포로 바꿔야
한다.

## 9. 검증 결과

| 검증 | 결과 |
|---|---|
| `compileall` | 통과 |
| 벤치마크 단위 테스트 | 5/5 통과 |
| 전체 프로젝트 회귀 테스트 | 143/143 통과, 약 20.7초 |
| `git diff --check` | 통과 |
| JSONL→CSV report | 평지 3그룹, 계단 9그룹, 강건성 3그룹, 전환 2그룹 생성 |
| Ruff 정적 검사 | 현재 Python 환경에 Ruff가 설치되지 않아 실행하지 못함 |

단위 테스트는 perturbation의 비물리 입력 거부, 짧은 MuJoCo trial의 finite/JSON
직렬화, custom stair profile 복구, Wilson 구간과 JSONL/CSV 출력을 검증한다.

전체 테스트 통과는 headless 동역학과 API 회귀를 뜻한다. 장시간 GUI에서 실제
접촉·다리 배치·카메라를 눈으로 검증한 결과는 아니며, 필요하면 macOS에서
`mjpython`으로 별도 viewer 실험을 수행해야 한다.

## 10. 현재 결과를 논문에 사용하는 기준

현재 수치 자체를 최종 ICRA 표로 사용하면 안 된다. 실행 당시 revision은
`bb32236`이지만 worktree가 dirty였고, 결과 JSON의 `git_dirty`도 `true`다.
현재 결과는 코드 경로와 가설을 검증하는 개발 기록이다.

논문용 최종 실험은 다음 조건을 만족해야 한다.

1. MJCF, controller, benchmark를 하나의 깨끗한 Git revision으로 고정한다.
2. 질량·관성·joint zero·속도·stall/continuous torque·TPU 마찰을 실측 보정한다.
3. controller별 torque, maximum speed, control bandwidth와 duration을 맞춘다.
4. tuning seed와 evaluation seed를 분리하고 실험 전에 목록을 고정한다.
5. 평지 명령별 최소 20회 이상 또는 power analysis로 정한 표본 수를 수행한다.
6. 계단은 각 riser/tread에서 성공과 실패를 모두 남기고 반복 성공률을 보고한다.
7. 실물에서도 동일 명령·동일 형상으로 속도, 전류/전력, slip, 자세를 계측한다.
8. 시뮬레이션과 실물의 차이를 별도 sim-to-real 표로 보고한다.
9. 무편집 영상과 원본 로그를 trial ID로 연결한다.
10. traversal-only 시간과 준비·모드 전환을 포함한 end-to-end 시간을 분리한다.

특히 200 mm 계단의 `full-scone` 단독 성공은 후속 실험의 중심 가설로 삼을 수
있지만, 현재 단계에서 “SCONE 구조가 일반 hexapod/RHex보다 우수하다”는 결론은
도출할 수 없다.

## 11. 다음 실행 권장 순서

1. **모델 식별**: 실물 질량 중심, joint 방향·zero, actuator 속도/토크, TPU
   접촉 파라미터를 측정한다.
2. **평지 명령 grid**: idle, 전후, 좌우, 양방향 yaw, forward-turn을 조건당
   20회 이상 실행한다.
3. **동일 구동예산 ablation**: 세 controller의 제한을 일치시킨 별도 조건을
   추가한다.
4. **계단 경계 탐색**: riser/tread Cartesian grid에서 성공 경계와 95% CI를
   구한다.
5. **전환 반복**: 양방향 각 20회 이상 실행하고 peak tilt와 pose reacquisition
   실패를 함께 보고한다.
6. **실물 교차 검증**: 배터리 단독 운용, 2.0 m/s 주행, 0.7 m/s 보행, 15단
   연속 계단 영상과 원본 시간·거리·전력 로그를 benchmark trial ID와 연결한다.
7. **논문 표 생성**: 고정 revision의 JSONL만 모아 `benchmark report`로 표를
   만들고, 수기로 옮기지 않는다.

## 12. 결과 파일 보존 규칙

`benchmark/results/`는 생성 산출물이므로 기본적으로 Git에서 제외한다. 논문에
사용한 최종 결과는 다음 정보를 포함해 별도 immutable archive로 보존하는 것이
좋다.

- Git commit과 dirty 여부
- 실행 명령 전체
- Python, MuJoCo와 운영체제 버전
- MJCF checksum
- seed와 perturbation 값
- trial별 JSONL, 집계 CSV, 무편집 영상
- 실패 원인과 중단 여부

논문에는 집계 CSV만 남기지 말고 원본 JSONL과 실물 영상/센서 로그의 대응 관계를
함께 보존해야 한다.

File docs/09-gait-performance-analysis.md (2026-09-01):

# Non-RL·Residual RL 보행 성능 분석과 개선 로드맵

> 이름 변경 안내: 이 문서의 과거 `Non-RL` 수치는 현재
> `tripod-gait`에 해당한다. 아래 continuous-roll 과거 수치는 현재
> `roll-gait`이고, 새 `scone-gait`는 PPO/점접지 hybrid이므로 별도 비교한다.

## 1. 결론

Non-RL이 하드코드보다 느려야 하는 구조적 이유는 없다. IK를 쓰는 비용은 학습
FPS에는 영향을 주지만, 생성된 관절 목표를 같은 50 Hz로 전송한 뒤의 로봇 속도를
직접 제한하지는 않는다. 현재 느림은 다음 세 문제가 겹친 결과다.

1. **명령보다 작은 보폭 상한**: Non-RL 전후 stroke는 `60 mm`에서 포화된다.
2. **관절 속도 한계를 넘는 발 궤적**: 특히 ID 13–18 목표가 프로파일 속도보다
   빠르게 바뀌어 큰 추종 지연이 생긴다.
3. **기준 보행을 덮어쓰는 policy**: 보유 checkpoint의 deterministic action은
   평균 절댓값 약 `0.95`로 거의 전 관절에서 포화되어, 더 빠른 zero-residual
   기준 모션을 오히려 느리게 만든다.

따라서 단순히 cadence나 모터 speed 숫자만 올리는 방식은 맞지 않는다. 명령 범위,
접지 궤적, actuator-aware 시간 배분, residual 학습을 순서대로 다시 맞춰야 한다.

### 1.1 2026-09-01 비-RL 조종 경로 적용 결과

이 문서 아래의 60 mm/0.7 Hz 분석은 RL reference와 2026-08-31 기준을 설명하는
역사적 측정으로 그대로 보존한다. 최초 비-RL MuJoCo 조종 sweep의
80 mm/0.8 Hz, speed 160, acceleration 50은 평균 속도만 보면 나아졌지만 후속
방향 진단에서 다시 교체됐다. 현재는 90/70 mm, 1.0 Hz, 25 mm lift, profile
무제한, middle stiffness 2배다.

| 경로 | 평균 속도 | root Z 하방 변화 | 비고 |
|---|---:|---:|---|
| 이전 interactive tripod | 0.0639 m/s | 0 mm, 위로 +19.91 mm 변동 | speed100/acc20, 60 mm |
| 1차 tuned tripod | 0.1058 m/s | −0.10 mm | 유한 profile, 80 mm; 방향 흔들림으로 교체 |
| 현재 SCONE-tuned tripod | 0.1184 m/s | −0.02 mm | 8초, 역방향 3.7 mm, 측면 0.7 mm, yaw 1.17° |
| 현재 full-body `roll-gait` | 0.2093 m/s | −20.68 mm | 6초, lower 3.09회전, B +60° |
| hybrid `scone-gait`, 15.4M 최대 입력 | 0.1140 m/s | 양의 높이, min upright≈1.000 | 4초 +0.456 m, Y −13 mm, yaw −2.2° |

PPO/RL reference 값은 이 표로 자동 변경하지 않았다. 모든 후보·실패·phase
가설은 [`12-automatic-stair-demo-and-continuous-roll-rework.md`](12-automatic-stair-demo-and-continuous-roll-rework.md)에 있다.

## 2. 비교 대상부터 분리해야 한다

프로젝트에서 “하드코드”는 세 가지를 가리킬 수 있다.

| 이름 | 코드 경로 | 동작 |
|---|---|---|
| Legacy `Walk` | `src/locomotion/walk.py` | `time.sleep()`과 20° 위치 명령으로 한 stride씩 실행 |
| RL `hardcoded` reference | `SconeWalkEnv._reference_motion_degrees()` | 기존 tripod 동작을 연속 사인파로 만든 residual 기준 |
| 학습된 hardcoded policy | 위 기준 + PPO residual | checkpoint가 18개 관절 보정을 추가 |

Legacy, zero-residual reference, 학습된 policy는 같은 알고리즘이 아니다. 특히
학습된 결과가 느리다고 해서 Non-RL 기준 생성기 자체가 느리다는 뜻은 아니다.
아래 측정은 Standard 자세, 평지, 50 Hz policy/500 Hz physics를 공통으로
사용했다. 물리 profile benchmark는 `walking_speed=100`, XM acceleration 20을
별도로 적용했고, 기존 PPO checkpoint 비교는 실제 학습과 같은 무제한 simulation
profile을 사용했다. 두 결과를 섞어 checkpoint 성능으로 해석하면 안 된다.

## 3. 2026-08-31 재측정 결과

측정 기준은 commit `9fd774a` 위 working tree다. 현재 변경에는 말단 최저 패치
중심 지지점, 0.7 Hz cadence, 전후 60 mm/측면 50 mm 작업공간이 포함된다. 기존
PPO는 무제한 simulation profile에서 학습됐으므로 현재 RL reset도 그 동역학을
보존한다. 물리 profile 수치는 회귀 원인을 분리하기 위한 별도 진단이다. GUI와
headless 결과를 함께 사용했지만 실물 장시간 측정은 아니므로 절대 안전 성능으로
해석하지 않는다.

### 3.1 기준 모션만 비교하면 Non-RL이 더 빠르다

residual action을 전부 0으로 두고 seed 3/7/11의 10초 결과를 평균했다.

| 전진 명령 | RL hardcoded reference | Non-RL reference | Non-RL / hardcoded |
|---:|---:|---:|---:|
| `0.18 m/s` | `0.00721 m/s` | `0.04554 m/s` | `6.32×` |
| `0.30 m/s` | `0.01400 m/s` | `0.05521 m/s` | `3.94×` |

즉 현재 체감 속도 차이의 원인을 “IK라서 원래 느리다”로 결론 내릴 수 없다.
zero-residual Non-RL은 같은 물리 제한에서 오히려 더 빠르다.

### 3.2 현재 저장된 policy는 기준 모션을 느리게 만든다

hardcoded 기준 checkpoint를 seed 7, deterministic으로 10초 재생했다. 기준
선택 기능 도입 전 9.8M이 후속 15.4M·22.1M보다 빨랐고, action 포화는 모든 큰
checkpoint에 남아 있었다.

| checkpoint/동역학 | 명령 | 전진 속도 | 평균 `|action|` | 결과 |
|---|---:|---:|---:|---|
| hardcoded 9.8M / 학습 당시 | `0.18` | `0.0727 m/s` | `0.973` | 비교군 중 가장 빠름 |
| hardcoded 15.4M / 학습 당시 | `0.18` | `0.0509 m/s` | `0.975` | 전진 복구, yaw drift 잔존 |
| hardcoded 22.1M / 학습 당시 | `0.18` | `0.0175 m/s` | `0.975` | 후속 학습에서 성능 퇴행 |
| hardcoded 15.4M / 뒤늦게 물리 profile 강제 | `0.18` | `-0.0225 m/s` | `0.972` | 전진 명령에서 후진; 해당 변경은 되돌림 |

action 범위는 `[-1, 1]`이고 residual scale은 upper/middle/lower 각각
`±10°/±12°/±15°`다. 평균 절댓값이 `0.95`라는 것은 policy가 작은 보정을 하는
residual controller가 아니라 거의 항상 최대 관절 오프셋을 쓰는 별도 gait가
되었다는 뜻이다. 여기에 학습하지 않은 actuator profile까지 덧붙이면 위상 관계가
깨져 후진까지 발생한다. profile 회귀는 복구했지만 policy 포화와 yaw drift는
checkpoint 자체의 남은 문제다.

### 3.3 사용자의 “움직임 반경이 작다”는 판단은 일부 맞다

목표 관절각을 동일한 부채꼴 말단 support point의 body-frame 궤적으로 다시
변환했다.

| 기준 모션 | 명령 | 평균 전후 범위 | 다리별 최대 전후 범위 | 수직 범위 |
|---|---:|---:|---:|---:|
| Non-RL | CLI 최대 `0.18` | `60.0 mm` | `60.0 mm` | `35.0 mm` |
| hardcoded | `0.18` | `36.3 mm` | `54.4 mm` | `13.9 mm` |
| hardcoded | full 최대 `0.50` | `108.0 mm` | `156.1 mm` | `48.8 mm` |

일상적인 `0.18` 명령에서는 Non-RL 범위가 더 크지만, full curriculum의 큰
명령에서는 hardcoded upper 관절 `±20°`가 Non-RL의 고정 60 mm 상한보다 훨씬
큰 궤적을 만든다. 다만 hardcoded 궤적은 전후 동작과 비슷한 크기의 불필요한
측면 궤적도 만들고, 실제 actuator가 그 큰 사인파를 모두 추종하지 못한다.
“범위를 키우면 무조건 빨라진다”가 아니라 유효 전후 stroke와 추종 가능한 관절
속도를 함께 최적화해야 한다.

### 3.4 Non-RL 말단 관절 목표가 물리 프로파일보다 빠르다

CLI 최대 전진, 0.7 Hz, 60 mm/35 mm 궤적을 50 Hz로 생성한 target 분석이다.

| 관절 그룹 | 목표각 peak-to-peak 평균 | target 속도 p95 | target 속도 최대 | speed=100 한계 |
|---|---:|---:|---:|---:|
| upper, MX ID 1–6 | `18.4°` | `48.5°/s` | `60.0°/s` | `68.4°/s` |
| middle, XM ID 7–12 | `16.2°` | `73.3°/s` | `116.5°/s` | `137.4°/s` |
| lower, XM ID 13–18 | `43.8°` | `181.2°/s` | `279.1°/s` | `137.4°/s` |

upper/middle은 대부분 한계 안이지만 lower는 p95부터 한계의 `1.32×`, 순간
최대는 `2.03×`다. 실제 동역학에서 `0.30 m/s` 명령을 주면 lower의
target-to-setpoint p95 지연이 다리별 최대 약 `33.8°`까지 커졌다. 현재 알고리즘은
발끝의 매끄러운 Cartesian 곡선만 보장하고, 그 곡선을 만드는 각 관절의 속도와
가속도는 제한하지 않는다. 이것이 가장 직접적인 actuator 병목이다.

### 3.5 학습 명령 대부분이 같은 60 mm stroke로 뭉개진다

stance 시간은 `duty_factor / cycle_frequency = 0.5 / 0.7 = 0.714 s`다.
따라서 60 mm stroke가 포화되기 시작하는 순수 전진 명령은 이론상 약
`0.060 / 0.714 = 0.084 m/s`다. 그러나 curriculum은 최대 `0.30`, `0.40`,
`0.50 m/s`를 요구한다.

현재 분포를 10,000개 표본으로 계산하면 다음과 같다.

- `easy` 전진 표본의 `56.79%`가 이미 stride clipping에 걸린다.
- `full` 3축 균등 표본의 `99.71%`에서 한 다리 이상 clipping된다.
- `full` 표본의 `85.11%`는 여섯 다리가 모두 clipping된다.
- 평균 leg clip fraction은 `96.68%`다.

결과적으로 policy 관측에는 서로 다른 `0.1~0.5 m/s` 명령이 들어오지만 기준
보행은 거의 같은 60 mm 궤적을 낸다. 달성 불가능한 속도 오차를 residual만으로
메우라고 요구하는 셈이며, command-conditioned policy가 명령 크기를 학습하기
어렵다.

### 3.6 같은 `0.18` 명령인데 CLI와 RL의 발 들기 높이가 다르다

`step_height`는 현재 `activity = |command| / max_command`에 곱해진다.

- CLI Non-RL: `max_vx=0.18`, 명령 `0.18` → activity `1.0` → `35 mm`
- RL Non-RL: `max_vx=0.50`, 명령 `0.18` → activity `0.36` → `12.6 mm`

전후 stroke는 60 mm로 이미 포화되는데 발은 12.6 mm만 든다. 즉 큰 수평 이동에
비해 clearance가 부족해 발 끌림과 접촉 충격이 늘 수 있다. `activity`를 전체
curriculum 최대값이 아니라 실제 stride utilization 또는 별도 lift schedule로
계산해야 한다.

## 4. 알고리즘 구조의 핵심 한계

### 4.1 stance 발이 월드에 고정되지 않는다

현재 stance 목표는 매 frame마다 명목 body-frame 발 위치에 명령 속도로 계산한
offset을 더한다. touchdown 순간의 실제 world contact를 저장하지 않고, 측정된
body 속도나 slip을 다음 목표에 피드백하지도 않는다. 몸체가 예상보다 느리면 발이
지면에 고정되는 대신 계속 미끄러진다.

개선 방향은 touchdown에서 support point의 world 좌표를 저장하고, stance 동안
현재 body pose로 다시 변환한 target을 IK에 넣는 것이다. 여기에 측정 body 속도
오차를 이용한 Raibert형 foot-placement 보정을 더하면 open-loop command와 실제
이동량의 차이를 줄일 수 있다.

### 4.2 부채꼴 접촉을 고정된 점 하나로 근사한다

현재 개선된 support point는 한쪽 mesh vertex가 아니라 최저 0.1 mm 패치 중심이다.
이것은 lateral bias를 줄였지만, 관절이 움직여 부채꼴 자세가 바뀐 뒤에도 같은
local point를 발끝으로 사용한다. 실제 최저점과 접촉점은 부채꼴을 따라 이동한다.

3관절로 한 점의 xyz를 정확히 맞추면 말단 자세를 독립적으로 지정할 자유도는
남지 않는다. 따라서 다음 중 하나가 필요하다.

- 현재 관절 자세에서 실제 최저 contact 후보를 다시 선택하는 active support point
- 접촉 위치·법선·관절속도를 함께 최소화하는 constrained optimization
- 미리 계산한 contact-aware joint-space 궤적을 사용하고 Cartesian IK는 작은
  보정에만 사용

### 4.3 Cartesian minimum-jerk가 joint-space 제한을 보장하지 않는다

발끝 경로는 부드러워도 Jacobian이 나쁜 구간에서는 작은 발 움직임이 lower 관절의
큰 회전으로 바뀐다. 현재 damped least-squares IK는 위치 오차와 수렴만 보며
관절별 속도, 가속도, torque margin을 비용에 넣지 않는다.

필요한 것은 actuator-aware time scaling과 weighted/constrained IK다. 각 frame의
`dq = J⁺ dx`를 계산해 ID별 profile velocity/acceleration 한계를 넘으면 phase
증분이나 해당 축의 stroke를 줄여야 한다. 반대로 여유가 있는 구간에서만 cadence와
stride를 늘려야 한다.

### 4.4 RL 목표가 현재 기준 보행의 도달 범위와 맞지 않는다

Non-RL zero-residual의 실측 최대가 현재 약 `0.055~0.062 m/s`인데 full command는
`0.50 m/s`다. 목표가 너무 멀면 velocity reward가 넓은 오차 영역에서 작은 차이만
보이고, policy는 residual 포화로 다른 보상 항을 공략할 수 있다. 기존 policy의
평균 `|action|≈0.95`는 이 실패를 직접 보여준다.

## 5. 우선순위별 개선 계획

### P0 — 측정 기준과 checkpoint를 먼저 고정

1. reference, support point, actuator profile, reward를 하나의 환경 버전으로
   고정한다. 물리 profile 정책은 기존 checkpoint를 resume하지 않고 0 step부터
   별도 학습한다.
2. 학습 전·중·후에 같은 command grid와 seed로 다음 세 대상을 자동 비교한다.
   - hardcoded zero residual
   - Non-RL zero residual
   - PPO policy
3. checkpoint 승격 조건에 전진/측면/yaw 오차, neutral drift, action saturation,
   stride clip, joint tracking lag, contact slip을 모두 넣는다.
4. policy가 zero-residual baseline보다 나쁘면 “학습 step이 많다”는 이유만으로
   최신 checkpoint를 채택하지 않는다.

### P1 — Non-RL 궤적을 actuator/contact-aware하게 변경

1. lift activity를 stride utilization에서 계산하고, 보행이 시작되면 최소 clearance를
   보장한다.
2. IK 결과의 관절 속도·가속도로 phase를 time-scale한다. 먼저 lower p95 target
   속도를 `137.4°/s` 아래로 만드는 것이 목표다.
3. touchdown world anchor와 측정 body-velocity feedback을 추가해 stance slip을
   닫힌고리로 줄인다.
4. 고정 sector-tip point를 실제 active contact point 또는 contact-aware 사전
   궤적으로 교체한다.
5. 그 뒤에만 stride와 cadence를 joint limit sweep으로 확장한다. 이전처럼
   cadence만 1.4 Hz로 올리지 않는다.

### P2 — residual RL이 기준 모션을 보존하도록 변경

1. 첫 curriculum은 현재 달성 가능한 전진 범위, 예를 들어 `0~0.06 m/s`에서
   시작하고 baseline 개선이 확인될 때만 범위를 넓힌다.
2. residual scale을 현재 `10°/12°/15°`보다 작게 시작하고 학습 진행에 따라
   늘리는 curriculum을 사용한다.
3. `mean(|action|)`, `action saturation fraction`, baseline 대비 속도 개선량을
   TensorBoard와 checkpoint 평가에 기록한다.
4. reward는 절대 속도 추종뿐 아니라 `policy 결과 - zero-residual 결과`의 개선을
   평가하도록 별도 benchmark를 둔다. 학습 reward 자체를 바꿀 때는
   [`06-reward-function-guide.md`](06-reward-function-guide.md)의 한-family-at-a-time
   절차를 따른다.

### P3 — 실물 데이터로 시뮬레이터를 닫는다

1. ID별 step response에서 목표/현재 위치, 속도, 전류 또는 load, supply voltage를
   기록한다.
2. 실제 기계 hard stop과 안전 관절범위를 측정해 임시 `±60°/±90°`를 교체한다.
3. 말단 접촉점 영상 또는 접촉 표식으로 실제 sector support 위치와 slip을 측정한다.
4. 이 데이터로 profile speed, acceleration, PD gain, friction을 맞춘 뒤 동일
   command grid를 실물과 MuJoCo에서 비교한다.

## 6. 다음 변경의 합격 기준

다음 튜닝은 “보기에 빨라짐” 대신 아래 기준으로 판정한다.

| 지표 | 첫 목표 |
|---|---|
| Non-RL zero-residual 전진 | 현재 `0.055 m/s` 이상 유지하며 증가 |
| PPO policy | 모든 핵심 명령에서 자신의 zero-residual baseline 이상 |
| easy stride clipping | 현재 `56.79%`에서 `20%` 미만 |
| lower target 속도 | p95가 profile limit `137.4°/s` 이하 |
| lower profile lag | p95 최대 다리 `5°` 이하 |
| neutral drift | runtime neutral gate 적용 후 별도 허용치 이내 |
| slip·자세 | 속도 증가 때문에 기존 slip/upright 기준이 악화되지 않음 |

이 기준을 통과하기 전에는 full curriculum 장기 학습보다 P1의 궤적과 P2의 작은
명령 curriculum을 짧게 반복하는 편이 효율적이다.

## 7. 이번 분석에서 제외한 것

- 실제 SCONE 하드웨어의 장시간 보행 속도와 발열은 측정하지 않았다.
- MuJoCo GUI에서 사람이 키를 누르는 시간, terminal key-repeat, 카메라 체감은
  headless 수치에 포함되지 않는다.
- 현재 checkpoint는 최신 dynamics와 호환된 신규 학습 결과가 아니다.
- 마찰계수와 TPU 변형은 실제 측정으로 보정되지 않았다.

따라서 이 문서의 핵심 결론은 “현재 알고리즘 병목이 수치로 확인됐다”까지다.
실물 안전 속도를 바로 올려도 된다는 근거는 아니다.

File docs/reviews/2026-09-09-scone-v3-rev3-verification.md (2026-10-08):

# rev.3 독립 교차검증 보고 (2026-09-09)

대상 문서: `docs/30-scone-v3-design-plan.md`
SHA-256 `e8acb6aa97263f5a29e61ce416133aec96e0c6218980283d7bba60615ca48ae5`
(문서 §16.2 참조 스크립트가 자체 출력하는 값과 일치)

검증 방법: 문서 본문을 읽지 않고 §10 JSON과 §11 FK 정의만으로 독립 재계산한 뒤
문서 기재값과 대조. 재현 스크립트 `tmp/v3review/rev3-verify/verify_rev3_all.py`.
CAD·하드웨어·기존 산출물은 건드리지 않았다.

---

## 1. 판정 요약

| 구분 | 결과 |
|---|---|
| rev.3가 제시한 정정 수치 | **13/13 재현. 전부 정확** |
| §16.2 참조 스크립트 | 추출·실행 성공, `regression_status: PASS` |
| rev.3가 철회한 rev.2 결론 | **철회가 타당.** rev.2 실제 오류 3건 확인 |
| rev.3가 열어둔 §7.1 빈칸 | **풀었더니 현재 피치로는 전방 굴림 자세가 성립하지 않음** |
| 추가로 반영이 필요한 항목 | 4건 (§4) |

---

## 2. rev.3 정정 수치의 독립 재현

| 항목 | 문서값 | 독립 재계산 | 판정 |
|---|---:|---:|---|
| `L_link` | 195.307179 | 195.307179 | ○ |
| `phi_off` | 13.770009° | 13.770009° | ○ |
| `beta` (기준 자세) | −50.406090° | −50.406090° | ○ |
| `q1` | −64.176099° | −64.176099° | ○ |
| `arm` | 124.477485 | 124.477485 | ○ |
| `z_ground` / `z_axle` | −273 / −150.5 | −273 / −150.5 | ○ |
| 회전당 이동거리 (지지함수 적분) | 752.81 mm | 752.809 (n=4000) / 752.810 (n=12000) | ○ |
| 일정 반경 접지호 길이 | 481.056 mm | 481.056 | ○ |
| heave | 18.5636 mm | 18.5636 (해석해 `122.5 − 112.5·cos22.5°`와 일치) | ○ |
| 팁-팁 현 | 86.1038 mm | 86.1038 | ○ |
| 3점 반력 분담 | 26.2724 / 47.4552 / 26.2724 % | 동일 | ○ |
| 안정마진 (0,0) / (−5,+25) | 86.62 / 61.39 mm | 86.620 / 61.392 | ○ |
| 링크 `J` / `Z_v` / 질량 | 97492.6 / 3797.13 / 84.27 g | 97492.6 / 3797.13 / 84.272 | ○ |
| 링크 굽힘 σ / SF | 3.84 MPa / 12.5 | 3.836 / 12.51 | ○ |
| 링크 비틀림 접지점 변위 | 1.094 mm | 1.0938 | ○ |
| BOM 분류 | 1446 / 2285.2 / 568 / 270 | 동일 (합 4569.2) | ○ |
| 스테레오 지면 교점 | 219.2 – 3577.6 mm | 219.16 / 3577.6 | ○ |
| 고정중심식 `psi_max` 정확해 | 37.496° | 37.4957° | ○ |

### 2.1 rev.2의 실제 오류 3건 (rev.3의 지적이 옳다)

1. **링크 단면계수**: rev.2 §5.2는 `t = 2.8 mm` 폐단면이라고 쓰고 실제로는 v8 실측
   벽 `t = 4.84 mm`로 `Z = 5477`을 계산했다. `t = 2.8`의 올바른 값은 `Z = 3797.13`,
   따라서 SF는 18이 아니라 **12.5**다.
2. **BOM 분류**: rev.2의 "구조 2777 g / 전장 346 g"은 집계 스크립트의 키워드 필터
   오분류다. 올바른 분류는 **모터 1446 / 구조 2285.2 / 전장·센서·배터리 568 /
   배선·체결 270**이다. 합계 4569.2 g 자체는 맞다.
3. **링크 질량**: rev.2의 63.2 g은 25% 경량화를 가정한 값이다. D0의 무공 형상에서는
   **84.27 g**이며, 6개로 **+126 g** 차이가 난다.

---

## 3. rev.3 §7.1이 열어둔 빈칸 — 계산 결과

rev.3는 "고정중심식 `e(psi)`로 다리 간섭을 판정하지 말 것, 조향 시 다리 전체가
조향축 주위로 이동한다"고 지적하고 `psi_max`를 삭제했으나, **175 mm 피치가 성립하는지에
대한 답은 남기지 않았다.** rev.3 §11의 FK와 §10 JSON만으로 부채꼴 원판 포락
(반경 122.5, 두께 20, 중심 `p2`, 법선 `v_i`)의 쌍별 최소거리를 계산했다.

### 3.1 근본 원인

```text
조향축 → 접지점 거리 = (stage1_axis_x − steer_axis_x + stagger) + arm
                     = (108 − 50 + 0) + 124.477 = 182.5 mm
다리 종방향 피치      = 175 mm
```

**조향 스윙 반경(182.5)이 다리 피치(175)보다 크다.** 조향각이 커지면 인접 다리의
바퀴 중심이 서로를 향해 이동한다.

### 3.2 전방 굴림 자세(yaw = ±90°)가 성립하지 않는다

rev.3 §11이 명시한 대로 우측 다리는 `yaw = +90°`에서만 `u`가 `+y`가 되어 전방으로
구른다. 그 자세에서 우측 3다리의 부채꼴 중심은

| 다리 | 중심 (x, y, z) | 법선 |
|---|---|---|
| L1 | (50.0, 7.5, −150.5) | (−1, 0, 0) |
| L3 | (50.0, 207.5, −150.5) | (−1, 0, 0) |
| L5 | (50.0, 357.5, −150.5) | (−1, 0, 0) |

세 원판이 **같은 평면(x = 50)에 200 / 150 mm 간격으로 선다.** 원판 지름이 245 mm이므로

| 쌍 | 최소거리 |
|---|---:|
| L1–L3 | **1.8 mm** |
| L3–L5 | **0.2 mm** |
| L1–L5 | 105.0 mm |

**요크 스태거 25 mm는 yaw 관절 뒤에 있으므로 90°에서 x 분리를 전혀 만들지 못한다.**
rev.3 §7.1의 지적이 정확히 맞으며, rev.2의 "스태거 25 mm로 90° 간섭 해소" 주장은
철회가 옳다.

### 3.3 인접 다리 역조향 한계

전방-우(L5)와 중앙-우(L3)를 반대 방향으로 `±psi` 조향했을 때의 최소거리 (mm):

| 피치 | ±15° | ±20° | ±25° | ±30° | ±35° | ±40° |
|---:|---:|---:|---:|---:|---:|---:|
| **175** | 19.8 | 6.6 | 1.6 | 1.8 | 4.2 | 4.1 |
| 235 | 55 | 20 | **10.4** | 3 | 1.5 | 2 |
| 295 | 110 | 61 | 24 | **10.1** | 5 | 2 |

여유 10 mm 요구 기준 **피치 175 mm의 역조향 한계는 약 ±17°**다.
(비단조인 것은 조향각이 커지면 다리가 서로를 지나쳐 다시 벌어지기 때문이며,
그 구간은 통과 과정에서 이미 충돌한다.)

역조향은 예외 상황이 아니다. 굴림 역할 다리가 고정 조향각을 유지하는 동안 보행 역할
다리는 stance 중 yaw를 좌우로 스윕하므로, 위상에 따라 부호가 반대가 되는 구간이 반드시 있다.

### 3.4 해법 후보와 비용

| 안 | 내용 | yaw=90° 최소여유 | 인접 역조향 | 비용 |
|---|---|---:|---|---|
| (a) | 피치 175 → **280 mm** | 10.0 mm | ±25°에서 15 mm | 전장 425 → **635 mm**, 질량·관성 증가 |
| (b) | **스태거를 조향축으로 이동**: 중간다리 `steer_axis_x` 50 → 80, 요크를 30 mm 단축해 도달거리 유지 | **10.1 mm** | ±20° 10.2 / ±25° 1.7 mm — **개선 없음** | 거의 없음. half-track 257.5 불변, 중간다리 트레일 207.5 → 177.5 mm로 감소(조향토크도 감소) |
| (c) | **doc29 두 다리 구동**: 뒤 쌍만 yaw=90, 나머지 yaw=0 유지 | L1–L3 108.7 / L1–L5 61.0 / L3–L5 155.0 mm | 나머지가 ±20° 보행 스윕해도 75~207 mm | 굴림 다리 2개로 제한 |

**(b)와 (c)는 상호 배타적이지 않고 서로 다른 문제를 푼다.**
(b)는 `yaw = 90°` 정렬 자체를 가능하게 하고, (c)는 그 자세를 동시에 취하는 다리 수를
줄여 역조향 문제를 회피한다.

[`29`](../29-two-leg-sector-drive.md)가 측정한 "뒤 쌍만 굴려도 네 모서리의 97% 속도"는
액추에이션 절감 논거로 기록돼 있으나, 위 계산에 따르면 **현재 기체 크기에서 유일하게
기하적으로 성립하는 전방 굴림 구성**일 가능성이 있다. rev.3 §14.2의 P03(단일 다리
yaw → side*90°) 진단 경로에 **다중 다리 동시 90° 케이스**를 추가해야 한다.

---

## 4. rev.3에 추가 반영이 필요한 항목

### 4.1 752.81 mm/rev 의 물리적 분해 (§2.4)

```text
재료 외곽 호 길이   666.71 mm   (구름, 접선속도 있음)
팁-팁 현            86.10 mm   (팁 피벗, 굴림 접선속도 없음)
합계                752.81 mm  = 지지함수 적분값과 일치
```

**1회전의 11.4%가 구름이 아니라 팁 피벗이다.** slip ratio·추진력·COT 해석에서 이
구간을 굴림으로 취급하면 안 된다. §2.4는 752.81만 제시하고 이 분해를 주지 않는다.

### 4.2 상류 문서 `docs/26` §3.4 전파 (미반영)

`Δx_rev = 2πR·(θ_occ/360)·(1−s) = 0.481(1−s) m` 는 [`26`](../26-stair-and-hybrid-locomotion-theory.md)
§3.4에서 정의되어 §4의 slip·에너지 수지, [`28`](../28-scone-gait-v2-role-split-rolling.md),
[`29`](../29-two-leg-sector-drive.md)로 전파되어 있다. rev.3는 v3 문서 안에서만 명칭을
정정했다.

**v2 형상(로브 없는 순수 225° 부채꼴)의 올바른 값도 481이 아니다:**

| | 회전당 이동거리 | heave |
|---|---:|---:|
| v2 지지함수 적분 (정답) | **707.41 mm/rev** | 75.59 mm |
| docs/26 §3.4 기재값 | 481.06 mm/rev (**−32.0%**) | — |

ICRA 제출본에 이 값이 들어간다면 반드시 정정해야 한다. rev.3에 "상류 문서 정정 필요"
항목을 추가할 것을 권한다.

### 4.3 로브 팁의 접촉면이 TPU 모서리다 (§3.4 LC06 보완)

`nose_fillet = 0`인 D0에서 팁의 반경은 타이어 112.5 / PLA 102.5다. 즉 **개구를 넘어가는
동안 전 하중이 10 mm 두께 TPU 모서리에 실린다.** §3.4 LC06은 "양쪽 로브 팁 각각에
`3*N_ref`"를 정의했지만 접촉면 재질·국부 접촉응력·반복 마모 항목이 없다.

이는 D1 필렛의 근거이자 I03(타이어 셀·고정 방식) 요구사항의 근거다. LC06에
**접촉 재질과 접촉 면적 산정 근거**를 명시적으로 추가할 것을 권한다.

### 4.4 D0는 설계상 G05 관성 목표를 넘을 가능성이 높다 (예고 필요)

D0는 포켓 0 / 구멍 0 / 반경추종 림·립이므로 rev.2 형상보다 반드시 무겁다.
§10 JSON 값으로 직접 적분한 결과:

| 항목 | rev.2 표기 | D0 계산 |
|---|---:|---:|
| 부채꼴 판 | 139.8 g | **182.2 g** |
| 타이어 | 63.8 g | 63.1 g |
| 다리당 | 203.6 g | **245.3 g** |
| 6다리 합 | 1.222 kg | **1.472 kg** (+250 g) |
| 스핀 관성 | 2.104e-3 | **≈2.225e-3 kg·m²** |
| 링크 6개 | 379.2 g | 505.6 g (+126 g) |

- **스핀 관성 2.225e-3 > G05 후보 목표 2.2e-3** → G05 관성 항목 FAIL 예상
- 위 두 항목만으로 총질량 **약 4.945 kg > 상한 후보 4.75 kg** → G05 질량 항목 FAIL 예상

rev.3 §15.2는 "목표를 몰래 완화하지 않는다"고 옳게 규정했다. 다만 **D0가 이 두 목표를
넘을 것이 계산상 이미 예측된다는 점**을 §8.4나 §15.2에 예고해 두면, 다음 에이전트가
G05 FAIL을 구현 오류로 오인해 되돌아가는 낭비를 막을 수 있다. FAIL의 원인은 D0의
의도적 단순화(무공)이며 D1 경량화로 해소할 항목이다.

---

## 5. 검증 범위의 한계

- 부채꼴을 **반경 122.5 / 두께 20의 완전 원판 포락**으로 근사했다. 실제 45° 개구를
  고려하면 특정 `q2` 조합에서는 여유가 더 클 수 있다. rev.3 §7.2 항목 4의
  "보수적 포락 우선, 겹친 쌍만 상세 검사" 절차와 같은 방침이다.
  **다만 굴림 중에는 `q2`가 연속 회전하므로 포락 충돌 = 실제 충돌이다.**
- 원판 간 최소거리는 림·중심면 샘플링(원주 160~200점)으로 구했다. 관통 깊이는 계산하지
  않았고 부호만 신뢰한다.
- 모든 계산은 기준 `q1`(스탠스 자세) 고정이다. 스윙 다리는 z로 분리되므로 여유가 커진다.
  최악은 두 다리가 모두 스탠스인 경우이며 그것이 위 결과다.
- 구조·전원·센서 관문(G06/G08/G09)은 검증하지 않았다. rev.3가 BLOCKED로 둔 상태가 옳다.

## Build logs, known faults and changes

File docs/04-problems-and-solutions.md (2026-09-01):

# 문제와 해결 과정

이 문서는 코드, 테스트, [`08-rl-development-log.md`](08-rl-development-log.md), Git 기록, 논문 증거 계획을 함께 비교해 정리했다. 과거 진단이 현재 구현과 다르면 현재 코드 상태를 별도로 적었다.

## 1. floating-base 모델이 바닥으로 무너지는 문제

### 증상

- floating base를 켜면 초기화 직후 몸체가 바닥으로 내려앉거나 관절이 목표를 유지하지 못했다.
- 겉으로는 PID gain 문제처럼 보였지만 gain만 높여도 안정적으로 해결되지 않았다.

### 진단

- visual mesh와 collision mesh가 섞여 불필요한 접촉이 발생했다.
- 모델의 초기 qpos가 서 있는 자세가 아니었다.
- position actuator가 물리적인 motor 한계를 우회하거나, 반대로 motor torque가 현재 중량을 버티지 못했다.
- floor 높이를 하드코딩하면 메시 원점과 실제 접촉 최저점이 맞지 않았다.

### 해결

- tire와 필요한 body geom만 collision group으로 분리하고 visual geom의 contact를 끈다.
- controller 생성 시 Standard 계열 안정 자세를 qpos에 seed한다.
- floating freejoint 높이를 최저 contact mesh와 floor 기준으로 조정한다.
- position actuator 대신 motor actuator + `DCMotorPID`를 사용해 12 V, stall torque, no-load speed를 반영한다.
- floor를 contact mesh의 최저 정점에서 자동 계산한다.

### 현재 상태

시뮬레이션의 초기 안정성은 개선되었지만 collision geometry와 질량/마찰의 실제 측정값은 더 검증해야 한다. gain을 올리는 것보다 actuator saturation, payload, 접촉 형상을 함께 확인해야 한다.

## 2. 왼쪽 다리의 방향과 대칭 문제

### 증상

같은 raw 목표를 주었는데 좌우 다리가 같은 기하학적 방향으로 움직이지 않거나, 특정 관절 단계만 거울상과 반대로 움직였다.

### 실패했던 접근

과거에는 actuator ID 배열을 mirror pair로 통째로 재배열하는 방법을 검토했다. 그러나 좌우 반전은 모든 관절에 동일하지 않고 stage별 joint axis가 다르므로, 전역 ID swap은 일부 관절을 고치는 대신 다른 관절을 틀리게 만든다.

### 해결

- Fusion/MJCF의 실제 joint axis를 단계별로 검사한다.
- 왼쪽의 필요한 joint(`M02`, `M04`, `M06`, `M14`, `M16`, `M18`)만 XML axis에서 보정한다.
- 시뮬레이터는 배열 위치가 아니라 actuator 이름과 연결 joint로 매핑한다.
- 실제 Dynamixel controller의 ID/명령 변환은 변경하지 않는다.

### 현재 상태

현재 코드는 과거의 고정 mirror-pair remap을 사용하지 않는다. 좌우 보정은 모델 계층에 있으며, 최종 실물 캘리브레이션 전까지 하드웨어 방향 변환을 성급히 추가하면 안 된다.

## 3. Fusion 부품 번호와 모터 ID의 불일치

### 문제

CAD export 이름, 다리 번호, actuator ID가 서로 다른 규칙을 사용하면 메시와 joint를 잘못 연결하기 쉽다.

### 해결

- MJCF joint는 `M01` … `M18`, actuator는 `A01_...` prefix를 사용한다.
- 코드의 다리→모터 규칙은 `(leg, leg+6, leg+12)`로 한곳에 둔다.
- model/kinematics/controller 모두 이름 조회를 사용하고 XML element 순서에는 의존하지 않는다.
- export report는 provenance 진단에만 쓰고 런타임 모델 입력으로 취급하지 않는다.

## 4. 물리 loop가 멈춘 것처럼 보이는 문제

### 증상

시뮬레이션 viewer와 키보드 CLI를 함께 실행할 때 화면이 멈추거나 입력 반응이 크게 늦었다.

### 원인

물리 update의 tight loop가 lock/CPU를 계속 점유해 viewer와 CLI thread가 실행될 기회를 잃었다.

### 해결

- MuJoCo timestep을 기준으로 실시간 pacing한다.
- terminal 입력은 공통 CLI thread 한 곳만 소유한다.
- controller lock은 상태 복사와 짧은 update 구간에만 사용한다.
- 종료할 때 neutral command를 명시적으로 전송한다.

## 5. Non-RL gait의 IK 불안정과 stride 범위

### 문제

큰 stride에서 일부 다리 IK가 수렴하지 않거나 관절 목표가 0–360 degree를 벗어났다. 실제 프로필과 시뮬레이션의 안전 범위도 달랐다.

### 해결

- damped least-squares, joint step 제한, backtracking을 사용한다.
- 모든 18개 결과가 finite, converged, 유효 범위일 때만 batch 전송한다.
- 실패한 다리는 마지막 유효 관절각을 유지한다.
- RL reference는 checkpoint 호환을 위해 0.7 Hz와 전후 `0.060 m`·측면
  `0.050 m`를 유지한다. 비-RL MuJoCo 조종은 후속 sweep에서 0.8 Hz와
  `0.080/0.060 m`로 분리했다.
- 복합 명령의 특정 다리 IK가 실패하면 nominal 발 위치 쪽으로 0.8배씩 최대 4회 backoff해 다시 푼다.
- 회전은 각 발의 위치에 `(-yaw*y, yaw*x)` 접선 속도를 더해 만든다.

초기 sweep는 RL 환경의 무제한 관절 profile 속도를 사용해 1.4 Hz를 잘못 채택했다. 실제 CLI와 같이 `walking_speed=100`으로 초기화한 별도 controller에서 6초간 최대 전진을 비교하면 1.4 Hz는 `0.0143 m/s`, 0.8 Hz는 `0.0502 m/s`였다. 또한 support point를 말단 패치 중심으로 교정하고 0.7 Hz를 적용했다. 같은 물리 profile의 Standard zero-action 500-step에서 Non-RL은 `0.05602 m/s`, hardcoded는 `0.01633 m/s`였고 slip penalty도 Non-RL이 약 42% 작았다. 다만 이 profile을 기존 PPO 재생에 뒤늦게 강제하면 학습 동역학이 달라져 15.4M policy가 전진 대신 후진했다. RL reset은 기존 checkpoint 호환을 위해 무제한 profile을 유지하고, 물리 profile 학습은 별도 버전으로 0 step부터 시작해야 한다. Sport는 느려 Standard를 권장한다.

## 6. body velocity 좌표계 오류

### 문제

MuJoCo/Fusion 모델의 local 축을 그대로 body velocity라고 가정하면 로봇이 회전했을 때 전진·측면 속도 부호가 틀어진다. 이 오류는 reward가 실제 이동 방향과 반대로 정책을 강화할 수 있어 특히 위험하다.

### 해결

- freejoint/world velocity를 명시적으로 구한다.
- body orientation의 역회전을 적용해 world vector를 body frame으로 변환한다.
- forward/reverse/yaw reference motion의 부호를 별도 테스트로 고정한다.

## 7. RL 보상의 정지·높이·중복 계산 문제

### 과거 문제

- 높이 오차의 양쪽을 벌주면 약간 높아지는 동작도 불필요하게 감점됐다.
- 일반 velocity reward만으로는 zero command에서 작은 진동과 residual action을 충분히 억제하지 못했다.
- 세부 term과 aggregate term을 모두 합하면 같은 reward가 두 번 계산될 위험이 있었다.
- heading 정보가 관측에 없어 yaw-rate가 0인 경우 장기 heading drift를 직접 보정하기 어려웠다.

### 해결

- height penalty는 기준 높이 아래로 내려간 양만 제곱한다.
- idle 판정, 작은 sigma의 idle velocity tracking, idle action penalty를 추가한다.
- reward 합계는 `velocity`, `direction`, `stability`, `damping` aggregate 네 값만 한 번씩 더한다. 세부 term은 진단 로그용이다.
- 관측에 heading error의 `sin/cos` 두 항을 추가해 68→70차원으로 확장했다.
- 구형 68차원 policy는 replay adapter만 제공하고 새 환경 학습에는 연결하지 않는다.
- neutral command에서는 `NeutralResidualGate`가 residual을 즉시 억제하거나 감쇠한다.

현재 정확한 수식과 가중치는 [보상함수 수정 가이드](06-reward-function-guide.md)를 기준으로 한다.

## 8. 접지 미끄러짐 측정의 부정확성

### 문제

body center velocity나 단순 foot body velocity는 실제 타이어-지면 접촉점의 미끄러짐을 나타내지 못한다.

### 해결

- MuJoCo contact에서 tire contact point와 normal force를 찾는다.
- contact point Jacobian으로 해당 점의 world velocity를 계산한다.
- normal 성분을 빼고 접선 속도만 남긴다.
- `1 N` 이상의 접촉만 사용하고 작은 deadzone 뒤 slip penalty를 계산한다.

## 9. checkpoint 손상과 동시 접근

### 문제

학습이 ZIP을 쓰는 중 원격 watcher가 읽거나, 네트워크 다운로드가 끊기면 불완전한 checkpoint가 정상 파일 이름으로 남을 수 있다.

### 해결

- 임시/`.part` 파일로 먼저 저장·다운로드한다.
- ZIP 필수 entry를 검사한다.
- 검증 뒤 `os.replace` 계열의 원자적 교체를 사용한다.
- resume pointer도 임시 파일 뒤 교체한다.
- reset은 기존 run을 삭제하지 않고 `.reset_backup`으로 이동한다.
- 원격 pause는 우선 SIGTERM으로 정상 저장 기회를 주며 즉시 SIGKILL하지 않는다.

## 10. 역사 문서와 현재 코드의 불일치

### 발견된 예

- 개발 기록의 일부 reward weight는 현재 `RewardConfig` 기본값과 다르다.
- 구형 논문과 아카이브에는 속도가 `0.05`, `0.07`, `0.5`, `0.7 m/s` 등 서로 다르게 기록되어 있다.
- ICRA 초안의 정량 결과는 아직 `TODO`이고 evidence matrix가 완성되지 않았다.
- 구형 SCONEv1 코드는 AX/MX 혼합, 재귀 gait, MobileNetSSD 카메라를 포함하지만 현재 SCONEv2 runtime 구조가 아니다.

### 문서화 원칙

- 실행 동작은 현재 코드와 테스트를 기준으로 설명한다.
- 논문 수치는 원 로그·영상·실험 설정으로 재구성되기 전에는 확정 주장으로 쓰지 않는다.
- history는 “왜 현재 구조가 되었는가”를 설명하는 근거로만 사용한다.

## 11. 시뮬레이션 모드 전환과 Drive 흔들림

### 문제

- 고정 sleep만 사용한 Walk→Drive→Climb 전환은 물리 관절이 목표에 도달하기 전에 다음 단계로 넘어갈 수 있었다.
- MuJoCo의 좌우 말단 관절축은 같은 raw velocity가 같은 지면 이동을 뜻하지 않아 Drive가 서로 밀어내는 방향으로 돌 수 있었다.
- Drive 중 하중을 받는 1단 관절(ID 7–12)이 목표 주변에서 흔들렸다.
- Standard 프로필의 기존 Climb 준비각은 Drive 중앙 자세에서 발을 들어 올리는 방향과 맞지 않았다.

### 해결

- `SCONE.initialize()`가 ID 7–18 XM을 position mode로 명시하고, 실제 controller도
  present-position 목표 도달을 기다리게 했다. Drive 진입 때 ID 7–12의
  mode/torque/profile/goal/present register를 read-back해 설정 오류를 분리한다.
- 시뮬레이션의 짝수 말단 ID 속도 부호를 뒤집어 좌우 바퀴의 지면 이동 방향을 맞춘다.
- Drive에 들어간 동안만 ID 7–12의 `kd`를 2배로 적용하고 Walk/Climb에서 복구한다.
- 시뮬레이션 Climb 준비각만 160°로 보정하고, 실물의 검증된 프로필 명령은 변경하지 않는다.

측정 sweep에서 2배 댐핑은 기본값 대비 1단 RMS 속도를 약 18%, 최대 각도 오차를 약 13% 줄였다. 4배는 진동 영역으로 넘어갔으므로 채택하지 않았다. 이 수치는 해당 MuJoCo 설정의 비교값이며 실물 성능 주장으로 사용하지 않는다.
실물 read-back이 통과해도 position gain/current/기계 유격은 아직 검사 대상이다.
따라서 흔들림을 자동으로 정상 판정하지 않고 진폭이 감쇠되는지 별도로 본다.

## 12. 병렬 환경 수가 실제 병렬이 아니었던 문제

기존 `num_envs`는 `DummyVecEnv` 안에서 환경을 순서대로 실행해 CPU 코어를 실질적으로 활용하지 못했다. 한 환경은 기존 동작을 유지하고, 두 개 이상은 `SubprocVecEnv` worker로 분리했다. SSH CLI도 물리 코어 하나와 메모리 2 GiB를 남긴 보수적 추천값을 계산하되 사용자가 수정할 수 있게 했다.

## 13. 계단 연속 회전과 후킹 assist 선택 문제

아래 120 mm까지의 비교는 최초 controller 선택 당시 기록이다. 현재
100/150/200 mm 재검증과 shallow-tread 실패 sweep는 이 절 끝과
11번 문서 12절을 기준으로 본다.

> **현재 구현 교정:** 이 절의 `ROLLING/TRIPOD_ASSIST` controller는 더 이상
> production `SconeStairClimber`가 아니다. 실제 계단 모션은 lower 여섯 개의
> 기하 위상을 동일하게 유지해야 한다는 정의에 따라, 2026-09-01에 하나의
> extended-position 위상 `θ`를 추종하는 방식으로 교체했다. 최신 원인·수식·
> 100/150/200 mm 공통 위상 결과는 11번 문서 13절, 옛 270° 앞다리 자세를
> 반영한 최종 결과는 14절을 기준으로 한다.

### 비교한 접근

- 여섯 C-sector를 같은 속도로 계속 돌리는 pure rolling
- 기존 Legacy `Climb`
- 항상 큰 middle 관절 동작을 쓰는 tripod hook
- 항상 작은 tripod 보조를 쓰는 hybrid
- 쉬운 단에서는 rolling을 유지하고 높은 단/정체에만 hybrid를 켜는 adaptive
  `scone-stair`

### 발견한 문제와 해결

- pure rolling은 `stairs-1/2`에서 가장 빠르고 적은 일을 사용했지만 120 mm
  rise가 있는 `stairs-3`에서 정체됐다.
- 기존 Legacy `Climb`은 현재 side-on procedural stair의 진행 phase와 맞지
  않아 세 preset 모두 제한 시간에 정상부 판정을 통과하지 못했다.
- 상시 tripod/hybrid는 높은 단을 통과했지만 쉬운 계단에서도 middle 관절을
  불필요하게 움직여 시간과 절대 기계 일이 증가했다.
- rolling 중인 여섯 하단 관절에 곧바로 서로 다른 tripod 속도를 섞은 초기
  prototype은 첫 지지 교대에서 옆으로 넘어졌다. assist 진입 전에 하단
  속도를 0으로 보내 phase를 동기화하고 0.18초 smoothstep을 적용했다.
- 알려진 높은 단 조건을 assist 종료 뒤에도 계속 평가하면 같은 구간에서
  assist가 반복됐다. known pre-hook은 한 번만 사용하고 이후에는 정체
  detector만 재진입을 허용한다.

현재 높이에서는 100 mm만 pure/adaptive가 모두 4.920초에 통과했다. pure는
150/200 mm에서 실패했고 adaptive는 각각 12.682초/assist 2회,
14.394초/assist 3회로 통과했다. 200 mm는 기존 170--240 mm tread에서
실패해 350 mm support tread로 바꾼 조건이다. 이 결과는 현재 MuJoCo preset
한 번씩의 결정론적 비교로, 실물 성공률이나 일반 계단 보장이 아니다.
수식·전체 표·실패 로그·실물 진입 조건은
[`11-scone-stair-climbing.md`](11-scone-stair-climbing.md)에 있다.

## 14. 비-RL 보행의 처짐·속도·가짜 rolling 문제

### 증상

- 세 다리 support가 바뀔 때 MuJoCo 차체가 실물보다 크게 내려가거나 출렁였다.
- `tripod-gait`가 PPO보다 답답하고 최대 명령을 올려도 보폭이 거의 같았다.
- 기존 `scone-gait`가 lower를 약 30° 왕복할 뿐이라 일반 tripod와 외형·성능이
  비슷했고 C자 말단을 바퀴처럼 사용하지 못했다.

### 실패와 원인

- `qfrc_bias` 중력 feed-forward는 contact constraint와 PID 보상을 중복해 root
  높이와 middle tracking error를 악화시켜 제거했다.
- speed 175/200과 cadence 0.85/0.9는 더 높은 명령인데도 slip과 20–28 mm
  하방 drop 때문에 느려졌다.
- lower 여섯 개를 같은 phase로 연속 회전하면 135° 개구부가 동시에 지면을
  향해 root Z가 63.5 mm 빠졌다.
- 여섯 다리 arbitrary phase는 0.1835 m/s로 빨랐지만 44.4 mm lateral drift와
  upright 0.964로 기각했다.
- 후속 직진 진단에서 0.8 Hz/80 mm 경로는 최대 명령의 약 97% frame에서
  stride가 잘렸고 lower 목표가 nominal 대비 최대 약 94°까지 다른 IK branch로
  이동했다. 8초 동안 역방향 이동 24.5 mm, 측면 편향 51.8 mm, 최대 yaw
  3.38°가 측정되어 “평균 전진”만으로는 문제를 발견할 수 없었다.
- 최초 continuous-roll 구현은 18관절 `SconeGait` 결과 중 1–12번만 보내고
  13–18번 기본 보행 position을 버렸다. 그래서 상·중단 진폭도 25/4 mm로
  작고 화면에서는 사실상 말단 회전만 보였다.

### 해결

- 비-RL tripod를 1.0 Hz, 90/70 mm, lift 25 mm로 바꾸고 simulation profile
  limiter를 해제했다. 모터 PID·전압·토크 한계와 middle stiffness 2배는
  유지한다. PPO replay와 실물은 그대로다.
- 당시 interactive `scone-gait`를 연속 회전으로 만들었고, 현재는 의미를
  바로잡아 `roll-gait`/`RollGait`로 route해 lower를 velocity mode로
  연속 회전시켰다.
- `scone-gait` 기본 보행을 stride/lift 55/20 mm로 키우고, lower bounded 목표의
  시간 미분을 0.35배로 연속 회전 속도에 합성했다. 상단·1단·2단 기본 보행과
  회전이 동시에 남는다.
- tripod B `(2,3,6)` lower 시작각을 +60° 벌려 개구부 support phase를
  de-synchronize했다.
- RL의 bounded `SconeGait` reference는 checkpoint action 의미 때문에 보존했다.
- 자동 계단 데모를 조종 메뉴와 분리해 hardcoded/improved/compare를 입력 없이
  실행하게 했다.
- 새 `scone-gait`는 checkpoint 필수 supervisor로 재정의했다. 저속/yaw는 PPO,
  고속은 stance 55% point hold 뒤 late-stance와 무부하 swing에서 한 방향
  multi-turn sector roll을 누적한다. 이전 bounded 왕복의 cycle 순 회전량 0
  문제를 제거했다.

수정 후 tripod는 8초 0.9469 m(0.1184 m/s), 역방향 누적 3.7 mm, 측면
0.7 mm, 최대 yaw 1.17°였고 20초에도 측면 5.0 mm/IK 실패 0이었다.
full-body continuous roll은 6초 1.2556 m(0.2093 m/s), lower 평균 3.09회,
최소 upright 0.9847, IK 실패 0이었다. 전체 sweep과 식은
[`12-automatic-stair-demo-and-continuous-roll-rework.md`](12-automatic-stair-demo-and-continuous-roll-rework.md)에 있다.
최신 이름, 전환식과 15.4M 검증값은
[`14-roll-gait-and-hybrid-scone-gait.md`](14-roll-gait-and-hybrid-scone-gait.md)에 있다.
현재 multi-turn 검증은 4초 동안 lower 실제 342~466°, upper/middle
peak-to-peak 14~24°와 body-X +0.298 m를 동시에 측정했으며 termination은 0이다.

## 15. 남아 있는 기술 부채와 권장 순서

1. 실제 관절별 mechanical range와 zero offset을 측정해 임시 `±60°/90°` 제한을 교체한다.
2. link별 collision geom과 self-collision filter를 실제 형상에 맞게 검증한다.
3. 실물 IMU/odometry 기반으로 RL 관측과 reward에 대응하는 state estimator를 만든다.
4. motor 전류·전압·온도 안전 제한과 비상정지를 RL 배포 계층 앞에 둔다.
5. latency, sensor noise, friction, payload, motor strength randomization을 추가한다.
6. 통합 requirements의 버전 lock과 새 macOS/Linux 환경 설치 smoke를 자동화한다.
7. reward ablation과 같은-hardware 반복 실험으로 각 논문 주장을 검증한다.
8. 실물 stair rise/tread/nosing/friction과 모터 전류를 계측한 뒤
   `scone-stair`의 torque·support margin·비상정지를 재튜닝한다.

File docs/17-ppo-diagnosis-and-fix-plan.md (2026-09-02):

# PPO 진단과 개선 계획 (2026-09-01)

> 이 문서는 V2 도입 전 `walk_learn` 70차원 정책의 역사적 진단이다. 현재
> `walk_v2` 82차원 정책과 실행 중인 학습의 실제 분석은
> [`21-walk-v2-ppo-training-analysis.md`](21-walk-v2-ppo-training-analysis.md)를
> 우선한다.

대상: `src/rl/walk_learn.py`, `src/assets/model.xml`
증상: (1) 전진 시 뒤쪽 두 다리가 기여하지 않음 (2) 좌우 비대칭 (3) 왼쪽으로 편향
(4) 최대 속도가 낮음

검증 방법: `model.xml`을 MuJoCo 3.12로 직접 로드해 관절 축·자세·질량중심을 수치로
계산했다. 아래 "검증됨" 표시는 추정이 아니라 계산 결과다.

---

## 0. 먼저 배제한 것 (검증 결과 문제 없음)

### 기구 모델은 좌우 대칭이다 — 검증됨
몸체 좌표계에서 9개 좌우 관절 쌍의 회전축을 모두 비교했다. 거울면은 몸체 $xz$
평면($y\to-y$)이고, 축벡터(pseudovector) 거울상 판정 $(a_x,a_y,a_z)\to(-a_x,a_y,-a_z)$
에 대해 **9쌍 전부 MIRROR-OK**였다.

```
M01[-0,-0,-1] vs M02[-0,-0, 1]   MIRROR-OK      (몸체 관절)
M07[-.707,-.707,0] vs M08[.707,-.707,0]  MIRROR-OK  (중간 관절)
M13[.707,.707,-0] vs M14[-.707,.707,-0]  MIRROR-OK  (말단 호)
... 9/9 통과
```

`degrees_to_raw`는 모터 ID를 무시하므로(`controller.py:250`, `del motor_id`) 좌우에
**같은 각도를 주면 정확히 거울 자세가 나온다.** SPORT 스탠스에서 실제 접촉 중심을
비교하면 좌우 오차는 x 1.1 mm, y 1.2 mm, z 3.4 mm로 CAD 반올림 수준이다.

→ **비대칭은 기구가 아니라 학습 쪽 문제다.**

### 보상의 속도 측정점은 올바르다 — 검증됨
`root_body` 프레임 원점이 로봇 질량중심에서 평면상 0.157 m 떨어져 있어 처음에는
`mj_objectVelocity`가 코너 점의 속도를 보고할 것으로 의심했다. 수치로 확인한 결과
이 함수는 **질량중심 속도를 반환**한다(질량중심을 고정하고 yaw 0.5 rad/s를 주면
보고값 0.0005 m/s, 프레임 원점을 고정하면 0.0787 m/s). 문제 없음.

---

## 1. 즉시 확인할 것 — 학습과 재생의 기준 궤적이 다르다

`walk_learn.py:1475`

```python
def _resolve_reference_motion(command_name, selected):
    if selected is not None: return normalize_reference_motion(selected)
    if command_name == "enjoy": return "hardcoded"      # 재생 기본값
    return "tripod-gait"                                # 학습 기본값
```

policy는 `tripod-gait`(IK 기반 삼각보) 위에 residual을 얹도록 학습되는데, `enjoy`는
기본적으로 `hardcoded`(관절공간 사인파) 위에 그 residual을 더한다. **residual이
학습한 적 없는 base motion에 더해지고 있다.**

관측되는 증상 대부분이 이것만으로 설명될 수 있다. 재학습 없이 지금 바로 확인 가능:

```bash
python -m src.rl enjoy --reference-motion tripod-gait ...   # 학습과 동일 기준
python -m src.rl enjoy --reference-motion hardcoded   ...   # 현재 기본값
```

두 결과가 다르면 "학습 실패"가 아니라 재생 설정 문제다. **다른 어떤 수정보다 먼저
이것을 확인할 것.**

---

## 2. 최대 속도가 낮은 이유 — 명령이 기준 궤적의 6배다

학습용 `tripod-gait` 기준 궤적 설정 (`walk_learn.py:353`):

| 항목 | 값 |
| --- | --- |
| `cycle_frequency` $f$ | 0.7 Hz (명령과 무관하게 고정) |
| `max_stride` $s^{\max}$ | 0.060 m |
| `duty_factor` $D$ | 0.5 (`GaitConfig` 기본값) |

스트로크는 $s=Du/f$이고 $s\le s^{\max}$이므로 기준 궤적이 낼 수 있는 속도 상한은

$$u_{\max}=\frac{s^{\max}f}{D}=\frac{0.060\times0.7}{0.5}=\mathbf{0.084\ m/s}$$

그런데 명령 범위는 `CURRICULUM_RANGES`에서 easy 0.30, medium 0.40, full 0.50 m/s다.
**명령이 기준 궤적 능력의 3.6~6배다.**

속도 보상은 $\exp(-\|e\|^2/\sigma^2)$, $\sigma=0.25$이므로

| 명령 | 도달 가능 | 오차 | 속도 보상 |
| ---: | ---: | ---: | ---: |
| 0.30 m/s | ~0.084 | 0.216 | 0.47 |
| 0.50 m/s | ~0.084 | 0.416 | **0.06** |

residual($\pm10/12/15^\circ$)이 스트로크를 대략 배로 늘려도 0.15~0.20 m/s가 한계다.
즉 **고속 구간에는 gradient가 사실상 없다.** 정책은 속도를 포기하고 자세·행동
패널티만 최적화하는 것이 이득이며, 이는 "느리고 소극적인 보행"으로 나타난다.

`_advance_phase`는 모델 기준 궤적이 있으면 즉시 return하므로(`walk_learn.py:517`)
주파수가 명령에 따라 올라가지도 않는다.

---

## 3. 뒤쪽 다리가 기여하지 않는 이유 — 보상에 그럴 이유가 없다

세 가지가 겹친다.

1. **관측에 접촉 정보가 전혀 없다.** 70차원 관측은 몸체 속도/자세, 관절 위치·속도,
   이전 행동, 명령, 위상·헤딩 sin/cos뿐이다(`walk_learn.py:676`). 정책은 어떤 다리가
   지면에 닿아 있는지 **알 수 없다.**
2. **보상에 다리 기여 항이 없다.** 부하 분담, 접촉 스케줄, air-time, 발 clearance
   어느 것도 없다. `stance_contacts`는 진단 출력일 뿐 보상에 들어가지 않는다.
3. **행동 크기 패널티가 균등하다.** `action_magnitude_weight=0.25`가
   $\mathrm{mean}(a^2)$를 18관절 균등으로 벌한다. 어떤 다리를 쓰든 보상은 몸체
   속도 하나로만 측정되므로, **기여가 애매한 다리의 residual을 0으로 두는 것이
   엄밀히 최적**이다. 지금 보이는 현상은 학습 실패가 아니라 이 보상의 정확한 해다.

부수적으로, 몸체 좌표계에서 다리 힙 위치는 x = −0.005 / +0.125 / +0.255 이고
질량중심은 x = +0.124 로 정확히 가운데 쌍 위에 있다. 앞뒤 발자국은 질량중심 기준
∓0.33 m로 대칭이므로 **기하학적으로는 앞뒤 어느 쌍도 불리하지 않다.**

> 확인 필요: 몸체 +x가 전방인지 후방인지. 내부 탑재물 주석은 "front-to-rear" 순서로
> L1/L2 배터리(x=−0.005) → RPi → L3/L4 배터리(x=+0.125)를 배치한다고 적혀 있어
> **전방이 −x**임을 시사한다. 반면 RL과 gait 코드는 +x를 전진으로 사용한다. 이것이
> 뒤집혀 있으면 사용자가 "뒷다리"라고 부르는 쌍이 실제로는 선행 다리다.

---

## 4. 좌우 비대칭과 왼쪽 편향

기구가 대칭임을 확인했으므로 원인은 학습 설정에 있다.

### 4.1 대칭성을 강제하는 장치가 하나도 없다
미러 데이터 증강도, 대칭 손실도, 좌우 균형 보상도 없다. 좌우가 완전히 독립적인
파라미터로 학습되므로 PPO가 대칭해로 수렴할 이유가 없다.

### 4.2 초기 상태·도메인 랜덤화가 전무하다
`reset()`에서 랜덤화되는 것은 **보행 위상 하나뿐**이다(`walk_learn.py:958`).
초기 관절 섭동, 몸체 자세/헤딩 랜덤화, 외란 push, 질량·마찰·지연 랜덤화,
관측 노이즈가 전부 없다. 매 에피소드가 동일한 상태에서 시작하므로 한쪽으로 치우친
해가 한 번 형성되면 그것을 깨뜨릴 압력이 없다.

### 4.3 헤딩 보상이 너무 헐겁다
`heading_error_sigma = 0.60 rad = 34.4°`, `heading_weight = 0.75`.
20° 정상편차의 보상은 $\exp(-(0.35/0.6)^2)=0.71$로 거의 무료다. 게다가 yaw 항은
**각속도** 추종만 벌하므로 누적 헤딩 오차에 대한 복원력이 약하다. easy 커리큘럼은
yaw 명령이 0이라 헤딩 유지가 유일한 방향 신호인데 그 신호가 34° 폭으로 뭉개져 있다.

### 4.4 미러 증강에 필요한 사상 (검증된 대칭성 기반)
관절 축이 정확한 축벡터 거울상이고 각도 변환에 부호가 없으므로, 미러 사상은
**부호 없는 단순 치환**이다: 다리 $1\leftrightarrow2,\ 3\leftrightarrow4,\ 5\leftrightarrow6$,
즉 모터 ID $i\leftrightarrow i\pm1$ (각 6개 군 내부에서).

삼각보가 $\mathcal{T}_A=\{1,4,5\}$, $\mathcal{T}_B=\{2,3,6\}$이므로 이 치환은
**두 삼각보를 맞바꾼다.** 따라서 위상도 반주기 이동해야 한다.

70차원 관측에 대한 미러 연산자 $M$:

| 구간 | 내용 | 변환 |
| --- | --- | --- |
| `[0:3]` | 선속도 (극벡터) | $(+,-,+)$ |
| `[3:6]` | 각속도 (축벡터) | $(-,+,-)$ |
| `[6:9]` | 투영 중력 (극벡터) | $(+,-,+)$ |
| `[9:27]` | 관절 위치 | 치환 $P$ |
| `[27:45]` | 관절 속도 | 치환 $P$ |
| `[45:63]` | 이전 행동 | 치환 $P$ |
| `[63:66]` | 명령 $(v_x,v_y,\omega_z)$ | $(+,-,-)$ |
| `[66:68]` | $(\sin2\pi\phi,\cos2\pi\phi)$ | $(-,-)$ — 반주기 이동 |
| `[68:70]` | $(\sin e_\psi,\cos e_\psi)$ | $(-,+)$ |

행동(18차원)은 치환 $P$. 이 $M$으로 rollout을 복제해 배치에 추가하면 대칭성이
데이터 수준에서 강제된다.

---

## 5. PPO 하이퍼파라미터

`walk_learn.py:1294`

| 항목 | 현재 | 평가 |
| --- | --- | --- |
| `num_envs` | 4 | 다리 로코모션 기준 매우 적음 |
| `n_steps` | 1024 | rollout 4096 샘플/업데이트 |
| `total_timesteps` | 1e6 | 18-DoF 로코모션에는 1~2자릿수 부족 |
| `gamma` | 0.99 | 50 Hz에서 유효 지평 ~2 s. 보행 주기 1.43 s(0.7 Hz)의 1.4배뿐 |
| `ent_coef` | 0.005 | 탐색 부족 가능 |
| `net_arch` | 256×2 | 무난 |

`episode_seconds = 10`, `frame_skip = 10` → 에피소드 500 step. gamma 0.99의 지평이
보행 주기를 겨우 한 번 넘는 수준이라 "여러 주기에 걸쳐 멀리 가는" 전략이 평가되지
않는다.

---

## 6. 개선 계획 (우선순위)

### P0 — 재학습 없이 오늘 확인 (반나절)
1. **`enjoy`의 기준 궤적을 `tripod-gait`로 맞춰 재생.** 증상이 사라지는지 확인
   (§1). 사라지면 나머지 진단의 우선순위가 완전히 바뀐다.
2. **다리별 진단 로그**: 전진 명령에서 다리 1..6 각각의 접촉 시간 비율, 수직
   임펄스, 발 전후 변위 진폭을 기록. "뒷다리가 논다"를 정량화하고, 몸체 +x가
   전방인지도 이 로그로 확정된다.

### P1 — 속도 상한 해제 (재학습 필요, 설정만 수정)
3. **기준 궤적을 명령 범위에 맞춘다.** 둘 중 하나:
   - $f$와 $s^{\max}$ 상향: 예 $f=1.2\,$Hz, $s^{\max}=0.12\,$m → $u_{\max}=0.29\,$m/s
   - 또는 명령 범위를 기준 능력에 맞춰 하향(easy 0.10, full 0.20)
   지금처럼 6배 벌어진 상태로는 어떤 하이퍼파라미터도 소용없다.
4. **기준 주파수를 명령에 연동.** 모델 기준 궤적을 쓸 때도 활성도에 따라
   `cycle_frequency`를 올린다(현재 `_advance_phase`가 즉시 return).
5. **속도 커리큘럼**: 성공률에 따라 명령 상한을 점진 확대.

### P2 — 대칭성 (재학습 필요)
6. **§4.4의 미러 증강**을 rollout 버퍼에 적용. 가장 확실하고 비용이 낮다.
7. **초기 상태 랜덤화**: 관절 ±5°, 몸체 yaw 전 범위, 높이 ±1 cm, 초기 속도 소량.
8. **외란 push**: 1~3초마다 몸체에 임의 방향 임펄스.
9. **헤딩 보상 강화**: `heading_error_sigma` 0.60 → 0.15~0.25, 필요하면 헤딩 오차
   적분 항 추가.

### P3 — 뒷다리 참여와 효율
10. **관측에 접촉 정보 추가**: 6개 발의 접촉 불리언 + 정규화 수직력(12차원 추가,
    70 → 82). 정책이 다리 상태를 볼 수 없으면 다리 역할을 배울 수 없다.
11. **접촉 스케줄 보상**: 삼각보 위상과 실제 접촉의 일치도, 또는 air-time 보상
    (스윙 시간이 목표 구간에 들 때 +). 다리별로 주면 놀고 있는 다리가 직접 벌점.
12. **부하 분담 항**: 여섯 다리 수직 임펄스 분포의 균등도(엔트로피 또는 분산 벌점).
13. **`action_magnitude_weight` 재설계**: 균등 $\mathrm{mean}(a^2)$ 대신 실제
    전류/토크 기반 비용으로 교체하거나 0.25 → 0.05로 낮춘다. 현재 값은 "다리를
    쓰지 않는 것"에 직접 보상을 준다.

### P4 — 학습 규모
14. `num_envs` 4 → 64 이상(가능하면 수백), `total_timesteps` 1e6 → 5e7 이상.
15. `gamma` 0.99 → 0.995 (지평 4 s), 또는 `episode_seconds` 연장.

---

## 7. 실행 순서 제안

```
P0-1 재생 기준 통일 확인          ← 여기서 결론이 크게 바뀔 수 있음
  └ 증상 지속 시:
      P1-3 기준 궤적 속도 상한 수정  ← 속도 문제의 유일한 근본 원인
      P2-6 미러 증강                 ← 비대칭의 가장 저렴한 해결
      P3-10/11 접촉 관측 + 스케줄 보상 ← 뒷다리 참여의 유일한 직접 처방
      P4  규모 확대
```

P1-3과 P3-13은 서로 반대 방향으로 작용하므로 함께 바꿔야 한다. 속도 상한을 풀면서
행동 패널티를 그대로 두면 정책은 다시 "가만히 있기"로 수렴한다.

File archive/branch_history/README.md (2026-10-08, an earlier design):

# Branch history archive — 2026-10-09

최종 개발 브랜치는 **`main` 하나**다. 이전 시스템과 실험은 폴더·태그·Git bundle로 보존했다.
원래 브랜치 이름과 커밋의 전체 대응은 [branches.json](branches.json)에 기록했다.

The final development branch is `main`. Historical systems and experiments remain
available through source snapshots, annotated tags and local recovery bundles. No force push
was needed to consolidate the published `main` history.

| 이전 브랜치 / Previous branch | 보관 방법 / Preservation |
| --- | --- |
| `feature/scone-gait-v2` | 최종 `main`의 기존 소스·자료 및 커밋 이력 / Final source, materials and commit history in `main` |
| 원격 `main` / Published `main` | PR 병합 기록을 `main`에 병합; `archive/main_before_cleanup` 태그 / Merged history and archive tag |
| `rl` | `main`에 이미 포함; `archive/rl` 태그 / Already included in `main`, plus archive tag |
| `SCONEv2_old`, 이전 `develop` | [원래 시스템](../scone_v2/README.md), `archive/scone_v2` 태그 / Original system and archive tag |
| `scone-gait-v2` | [실험 파일](../experiments/scone_gait_v2/README.md), `archive/role_split_gait` 태그 / Experimental snapshot and archive tag |
| `dynamixel-mujoco` | [최종 패키지](../../packages/dynamixel-mujoco/README.md), `archive/dynamixel_mujoco` 태그 / Byte-identical package and standalone history tag |
| `backup/pre-media-cleanup-20260830` | 로컬 복구 bundle; 압축 전 영상은 추가 업로드하지 않음 / Local recovery bundle; original videos are not uploaded again |
| `worktree-wf_619614a6-1b7-5`, `worktree-wf_619614a6-1b7-6` | [미커밋 변경 보존본](../development_snapshots/20261009/README.md); 실제 작업 폴더는 같은 커밋의 detached HEAD로 유지 / Saved uncommitted changes and preserved detached worktrees |

`backup/pre-media-cleanup-20260830`에는 GitHub의 일반 Git 파일 크기 한도를 넘는
원본 영상이 있다. 따라서 그 브랜치만의 2개 커밋과 객체는 **로컬 전용 bundle**로 보존했다.
위치: `archive/project-closeout/20261009-branch-cleanup/pre-media-cleanup-20260830.bundle`.
이 파일은 GitHub에 올리지 않는다. 공개 저장소의 영상은 사용자가 이미 압축한 파일을 유지한다.
bundle의 선행 커밋 `444f7442195c3eaaeb17f68da881d20cf121c7e7`은 최종 `main` 이력에 포함되어 있다.

The pre-cleanup backup contains an original video exceeding GitHub's regular Git
blob limit. Its two unique commits and their objects are preserved in a local-only bundle,
with the prerequisite commit retained in `main`.
The bundle is excluded from GitHub uploads; the existing compressed videos are retained.

로컬 bundle을 가진 복제본에서 복원할 때는 다음 명령을 사용한다. 보관된 원래 커밋은
`f2801d24ad865311ad5041c3312cca4649c9a441`이다.

```bash
git bundle verify archive/project-closeout/20261009-branch-cleanup/pre-media-cleanup-20260830.bundle
git fetch archive/project-closeout/20261009-branch-cleanup/pre-media-cleanup-20260830.bundle \
  refs/heads/backup/pre-media-cleanup-20260830:refs/tags/restored/pre-media-cleanup-20260830
git worktree add --detach ../SCONE-pre-media-cleanup restored/pre-media-cleanup-20260830
```

`archive/`로 시작하는 이름은 **태그**이며 추가 개발 브랜치가 아니다.
태그를 확인하려면 `git tag --list 'archive/*'`를 사용한다.

[전체 종료 및 복원 안내](../../docs/31-project-archive.md)

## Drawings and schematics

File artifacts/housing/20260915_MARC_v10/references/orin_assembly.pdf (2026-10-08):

# nvPLOT 142-13768-1000-A04 21 Feb 2023 : Assembly TOP

U57

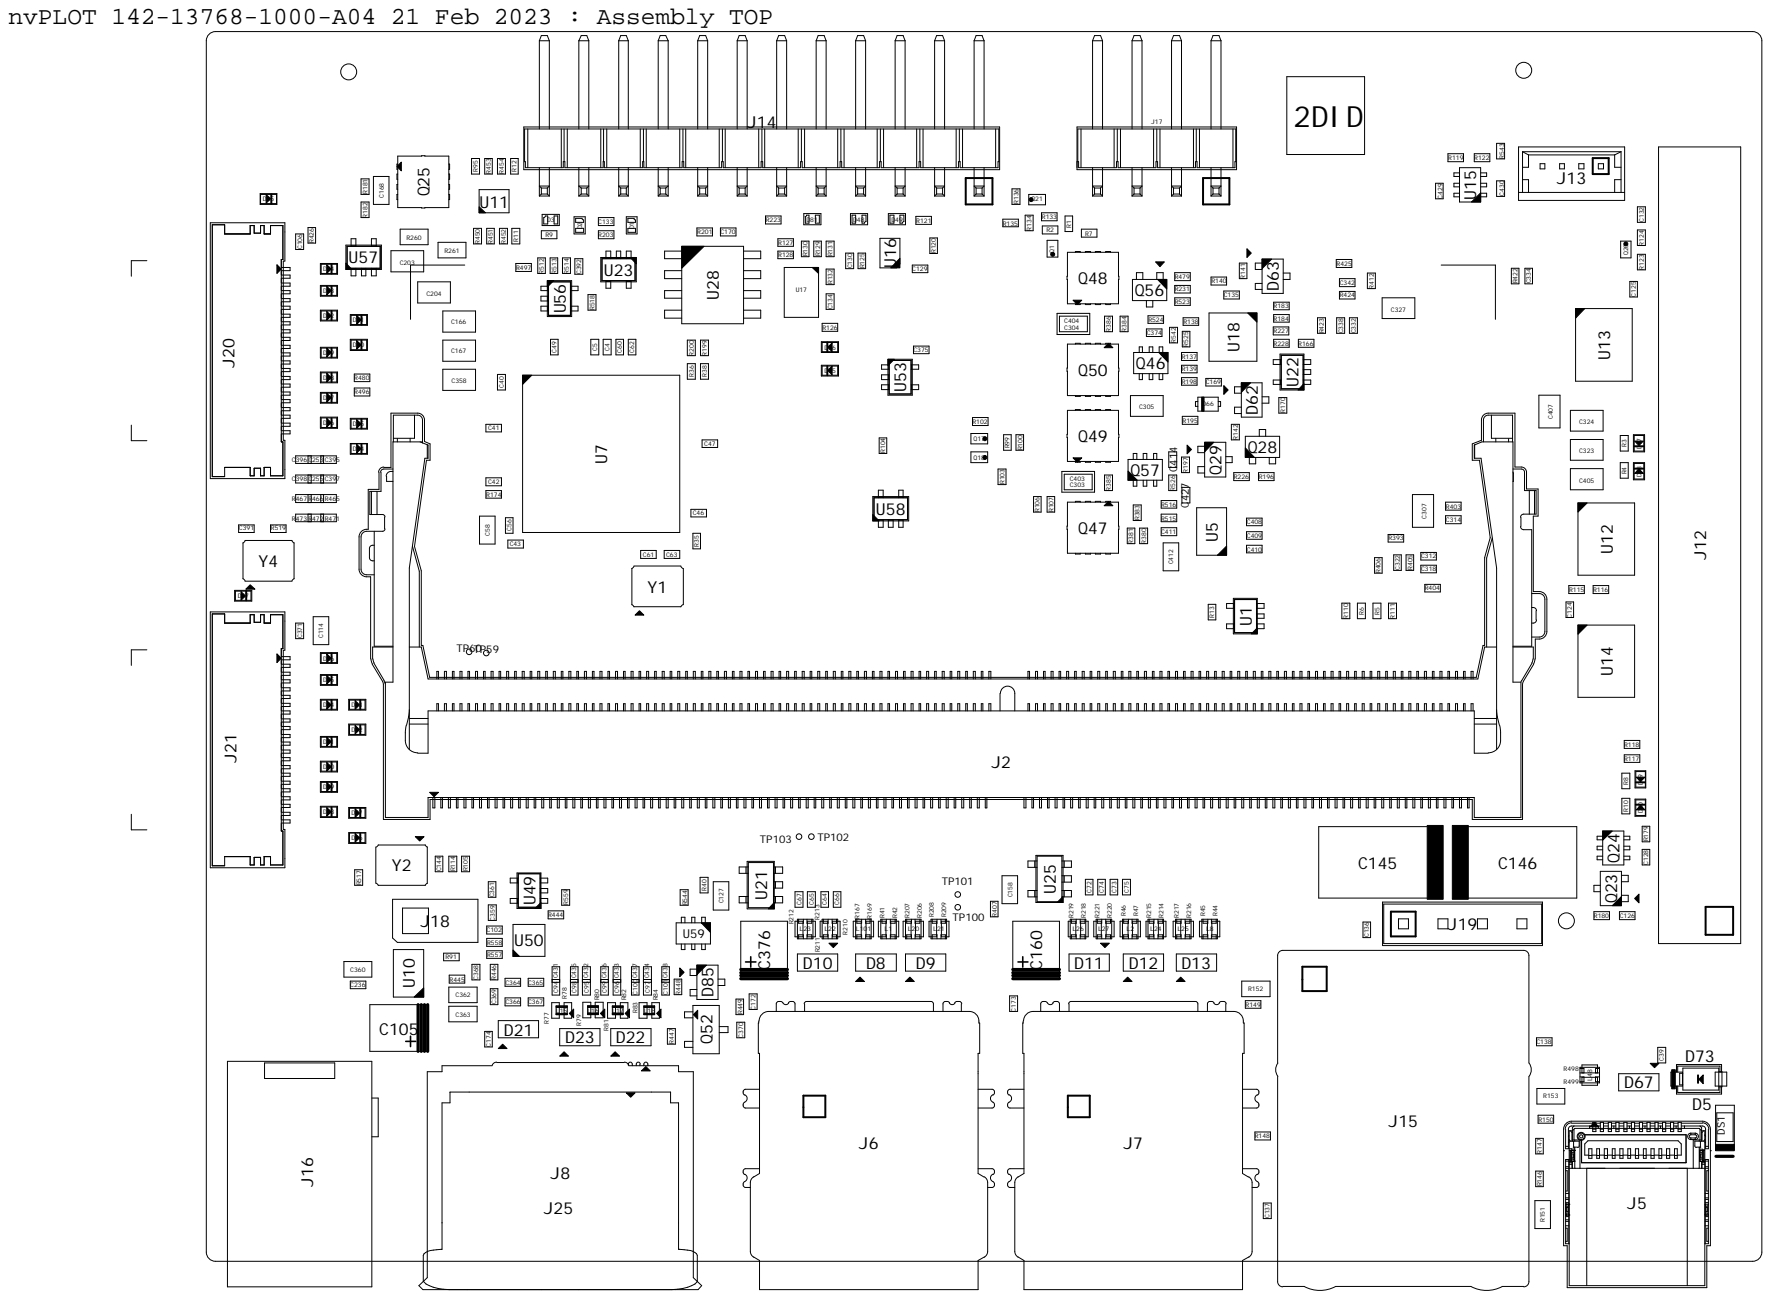
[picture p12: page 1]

# nvPLOT 142-13768-1000-A04 21 Feb 2023 : Assembly BOTTOM

D64

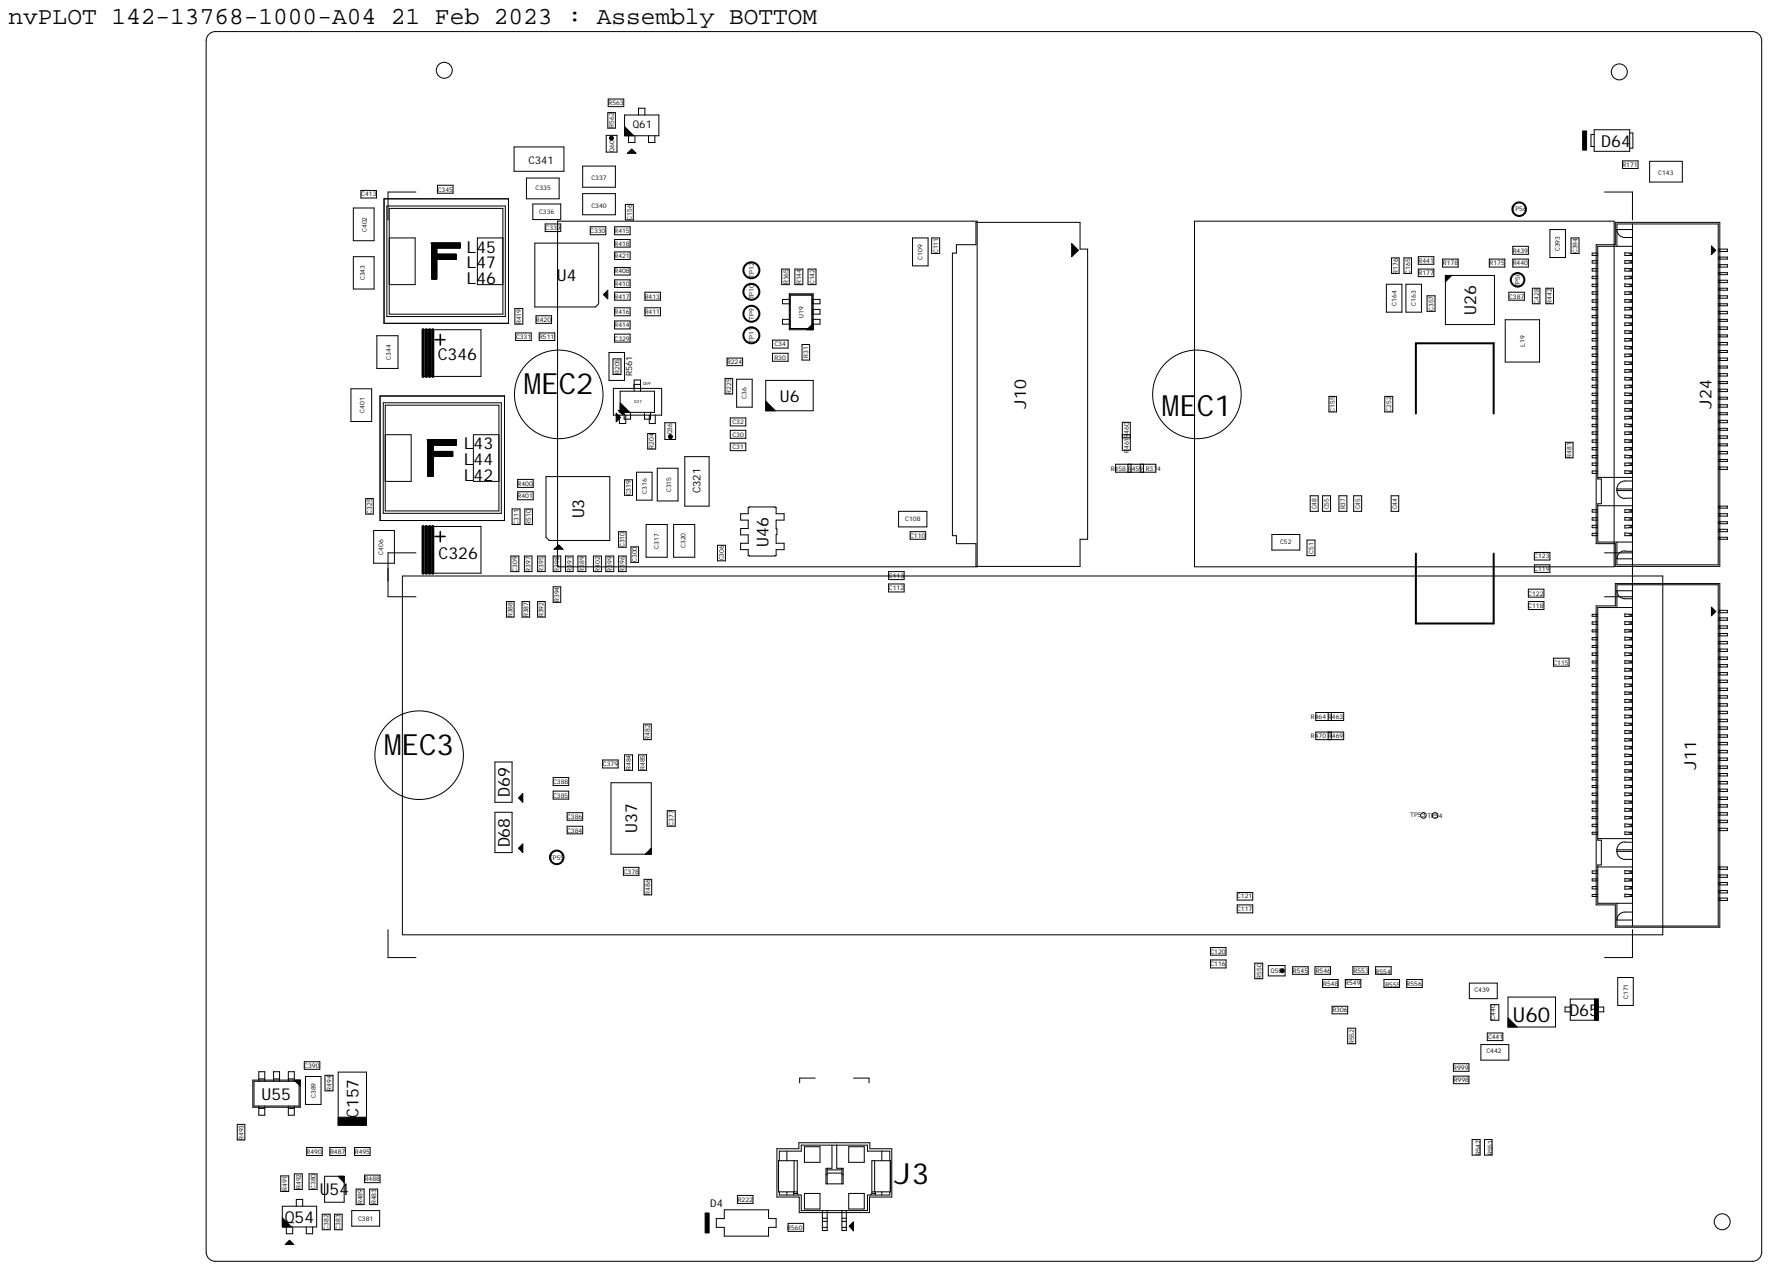
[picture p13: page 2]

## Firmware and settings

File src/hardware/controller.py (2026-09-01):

"""DYNAMIXEL-backed implementation of the SCONE controller API."""

from __future__ import annotations

import os
import time
from collections import defaultdict
from collections.abc import Iterable, Mapping

from dynamixel_sdk import GroupSyncWrite, PacketHandler, PortHandler

from .actuator import Actuator, model_for_id
from .actuator_control_table import Register
from .config import (
    DEFAULT_BAUDRATE as _DEFAULT_BAUDRATE,
    DEFAULT_DEVICE_NAME as _DEFAULT_DEVICE_NAME,
)


class ControllerError(RuntimeError):
    pass


class Controller:
    """Control the physical SCONE DYNAMIXEL bus.

    All register selection goes through :mod:`actuator_control_table`. Public
    motion code therefore works in terms of positions, speeds, and groups,
    without knowing protocol versions or register addresses.
    """

    DEFAULT_BAUDRATE = _DEFAULT_BAUDRATE
    DEFAULT_DEVICE_NAME = _DEFAULT_DEVICE_NAME

    def __init__(
        self,
        device_name: str | None = None,
        *,
        baudrate: int = DEFAULT_BAUDRATE,
        verbose: bool = True,
    ) -> None:
        self.device_name = device_name or os.getenv(
            "SCONE_DEVICE", self.DEFAULT_DEVICE_NAME
        )
        self.baudrate = baudrate
        self.verbose = verbose
        self._closed = False
        self._port_open = False
        self.port_handler = PortHandler(self.device_name)
        self._packet_handlers = {
            1.0: PacketHandler(1.0),
            2.0: PacketHandler(2.0),
        }

        self._log(f"opening {self.device_name}")
        try:
            opened = self.port_handler.openPort()
        except Exception as error:
            self._closed = True
            raise ControllerError(
                f"failed to open controller port: {self.device_name} ({error})"
            ) from error
        if not opened:
            self._closed = True
            raise ControllerError(f"failed to open controller port: {self.device_name}")
        self._port_open = True
        if not self.port_handler.setBaudRate(self.baudrate):
            self.close()
            raise ControllerError(f"failed to set controller baudrate: {self.baudrate}")
        self._log(f"ready at {self.baudrate:,} baud")

    def _log(self, message: str) -> None:
        if self.verbose:
            print(f"[HARDWARE] {message}")

    @staticmethod
    def _validate_id(motor_id: int) -> None:
        model_for_id(motor_id)

    def _handler(self, motor_id: int):
        return self._packet_handlers[model_for_id(motor_id).protocol_version]

    def _check(self, motor_id: int, comm_result: int, device_error: int) -> None:
        handler = self._handler(motor_id)
        if comm_result != 0:
            raise ControllerError(
                f"ID {motor_id}: {handler.getTxRxResult(comm_result)}"
            )
        if device_error:
            raise ControllerError(
                f"ID {motor_id}: {handler.getRxPacketError(device_error)}"
            )

    def _write(self, motor_id: int, register: Register, value: int) -> None:
        self._validate_id(motor_id)
        method = getattr(self._handler(motor_id), f"write{register.size}ByteTxRx")
        comm_result, device_error = method(
            self.port_handler, motor_id, register.address, int(value)
        )
        self._check(motor_id, comm_result, device_error)

    def _read(self, motor_id: int, register: Register) -> int:
        self._validate_id(motor_id)
        method = getattr(self._handler(motor_id), f"read{register.size}ByteTxRx")
        value, comm_result, device_error = method(
            self.port_handler, motor_id, register.address
        )
        self._check(motor_id, comm_result, device_error)
        return int(value)

    def _sync_write(self, values: Mapping[int, int], register_name: str) -> None:
        """Write one logical register to multiple motors, grouped by model."""

        grouped: dict[tuple[float, Register], dict[int, int]] = defaultdict(dict)
        for motor_id, value in values.items():
            model = model_for_id(motor_id)
            register = getattr(model.table, register_name)
            if register is None:
                raise ControllerError(
                    f"{model.name} does not support register {register_name!r}"
                )
            grouped[(model.protocol_version, register)][motor_id] = int(value)

        for (protocol, register), group in grouped.items():
            writer = GroupSyncWrite(
                self.port_handler,
                self._packet_handlers[protocol],
                register.address,
                register.size,
            )
            try:
                mask = (1 << (register.size * 8)) - 1
                for motor_id, value in group.items():
                    payload = (value & mask).to_bytes(register.size, "little")
                    if not writer.addParam(motor_id, payload):
                        raise ControllerError(
                            f"failed to queue sync write for actuator ID {motor_id}"
                        )
                comm_result = writer.txPacket()
                if comm_result != 0:
                    handler = self._packet_handlers[protocol]
                    raise ControllerError(handler.getTxRxResult(comm_result))
            finally:
                writer.clearParam()

    def set_mode(self, motor_id: int, mode: int) -> None:
        table = model_for_id(motor_id).table
        if table.operating_mode is None:
            return
        self.set_torque(motor_id, Actuator.Torque.OFF)
        self._write(motor_id, table.operating_mode, mode)
        self.set_torque(motor_id, Actuator.Torque.ON)
        self._log(f"ID {motor_id:02d}: operating mode -> {mode}")

    def set_all_mode(self, mode: int) -> None:
        # Only the distal wheel motors switch between position and velocity.
        for motor_id in Actuator.Index.LOWER:
            self.set_mode(motor_id, mode)

    def get_mode(self, motor_id: int) -> int | None:
        register = model_for_id(motor_id).table.operating_mode
        return None if register is None else self._read(motor_id, register)

    def set_speed(self, motor_id: int, speed: int) -> None:
        table = model_for_id(motor_id).table
        register = table.moving_speed or table.profile_velocity
        if register is None:
            raise ControllerError(f"ID {motor_id} has no profile speed register")
        self._write(motor_id, register, speed)

    def set_speeds(self, speeds: Mapping[int, int]) -> None:
        mx = {
            motor_id: value
            for motor_id, value in speeds.items()
            if motor_id in Actuator.Index.UPPER
        }
        xm = {
            motor_id: value
            for motor_id, value in speeds.items()
            if motor_id in Actuator.Index.XM
        }
        if mx:
            self._sync_write(mx, "moving_speed")
        if xm:
            self._sync_write(xm, "profile_velocity")
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

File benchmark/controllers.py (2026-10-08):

"""Controller adapters used by the paper benchmarks."""

from __future__ import annotations

import math
from dataclasses import dataclass
from typing import Protocol

import numpy as np

from src.hardware import Actuator
from src.locomotion import SconeGait, SconeGaitV2, SconeGaitV2Config, TripodGait, VelocityCommand
from src.simulation.core.cli_bridge import (
    SCONE_GAIT_SIMULATION_CONFIG,
    TRIPOD_GAIT_SIMULATION_CONFIG,
    configure_model_gait_controller,
)
from src.simulation.core.scone_rolling_gait import RollGait, RollGaitConfig

from .common import MetricsRecorder, SimulationTrial


CONTROLLER_CHOICES = (
    "articulated-walk",
    "distal-only-roll",
    "full-roll",
    "bounded-scone",
    "matched-articulated",
    "matched-distal-only",
    "matched-coordinated",
    "role-split-scone",
    "rewind-budget-scone",
    "rewind-distance-scone",
    "role-split-no-roll",
    "role-split-superposition",
    "role-split-no-reindex",
    "role-split-periodic",
)

MATCHED_CONTROLLER_CHOICES = (
    "matched-articulated",
    "matched-distal-only",
    "matched-coordinated",
)
MATCHED_ROLL_CONFIG = RollGaitConfig()


@dataclass(frozen=True)
class ControlDiagnostics:
    converged: bool = True
    stride_clip_fraction: float = 0.0
    ik_backoff_scale: float = 1.0


class BenchmarkController(Protocol):
    name: str

    def prepare(
        self,
        trial: SimulationTrial,
        *,
        recorder: MetricsRecorder | None = None,
    ) -> None: ...

    def update(self, command: VelocityCommand, dt: float) -> ControlDiagnostics: ...

    def stop(self) -> None: ...


def _diagnostics(sample) -> ControlDiagnostics:
    return ControlDiagnostics(
        converged=bool(sample.converged),
        stride_clip_fraction=float(sample.stride_clip_fraction),
        ik_backoff_scale=float(sample.ik_backoff_scale),
    )


def _phase_pose(planner: SconeGait, config: RollGaitConfig) -> np.ndarray:
    pose = planner.nominal_motor_degrees
    for leg in planner.TRIPOD_B:
        pose[11 + leg] += config.tripod_b_phase_offset_degrees
    return pose


def _configure_matched_position_path(
    trial: SimulationTrial,
    config: RollGaitConfig,
) -> None:
    trial.controller.set_all_speed(config.profile_velocity)
    trial.controller.set_accelerations(
        {motor_id: config.profile_acceleration for motor_id in Actuator.Index.XM}
    )
    trial.controller.set_gait_position_stiffness(
        config.middle_stiffness_multiplier
    )


def _acquire_phase_pose(
    trial: SimulationTrial,
    planner: SconeGait,
    config: RollGaitConfig,
    *,
    recorder: MetricsRecorder | None,
) -> np.ndarray:
    pose = _phase_pose(planner, config)
    _configure_matched_position_path(trial, config)
    trial.controller.set_positions(
        {motor_id: float(pose[motor_id - 1]) for motor_id in Actuator.Index.ALL}
    )
    raw_targets = {
        motor_id: trial.controller.degrees_to_raw(motor_id, float(pose[motor_id - 1]))
        for motor_id in Actuator.Index.ALL
    }
    if not trial.wait_until_raw_positions(
        raw_targets,
        tolerance=96,
        timeout=4.0,
        recorder=recorder,
    ):
        raise RuntimeError("matched controller phase pose did not settle")
    return pose


class ArticulatedWalkController:
    name = "articulated-walk"

    def __init__(self, trial: SimulationTrial, *, phase: float = 0.0) -> None:
        self.trial = trial
        self.phase = phase
        self.gait: TripodGait | None = None

    def prepare(
        self,
        trial: SimulationTrial,
        *,
        recorder: MetricsRecorder | None = None,
    ) -> None:
        del recorder
        configure_model_gait_controller(trial.controller)
        self.gait = TripodGait(
            trial.controller,
            trial.robot.profile,
            config=TRIPOD_GAIT_SIMULATION_CONFIG,
        )
        self.gait.reset(phase=self.phase)

    def update(self, command: VelocityCommand, dt: float) -> ControlDiagnostics:
        assert self.gait is not None
        sample = self.gait.update(command, dt=dt, send=True)
        return _diagnostics(sample)

    def stop(self) -> None:
        if self.gait is not None:
            self.gait.update(VelocityCommand(), dt=0.02, send=True)


class DistalOnlyRollController:
    """Lock proximal targets while only the six C-frames rotate."""

    name = "distal-only-roll"

    def __init__(
        self,
        trial: SimulationTrial,
        *,
        phase: float = 0.0,
        config: RollGaitConfig | None = None,
        recalibrate_phase_pose: bool = False,
    ) -> None:
        self.trial = trial
        self.phase = phase
        self.config = config or RollGaitConfig()
        self.recalibrate_phase_pose = recalibrate_phase_pose
        self.planner = SconeGait(
            trial.controller,
            trial.robot.profile,
            config=self.config.planner_config(),
        )
        self.planner.reset(phase=phase)
        self._filtered_velocity = np.zeros(6, dtype=np.float64)
        self._active = False

    def prepare(
        self,
        trial: SimulationTrial,
        *,
        recorder: MetricsRecorder | None = None,
    ) -> None:
        phase_positions = {
            motor_id: float(
                self.planner.profile.lower_initial_position
                + (
                    self.config.tripod_b_phase_offset_degrees
                    if motor_id - 12 in self.planner.TRIPOD_B
                    else 0.0
                )
            )
            for motor_id in Actuator.Index.LOWER
        }
        trial.controller.set_all_speed(self.config.profile_velocity)
        trial.controller.set_accelerations(
            {
                motor_id: self.config.profile_acceleration
                for motor_id in Actuator.Index.XM
            }
        )
        trial.controller.set_gait_position_stiffness(
            self.config.middle_stiffness_multiplier
        )
        trial.controller.set_positions(phase_positions)
        raw_targets = {
            motor_id: trial.controller.degrees_to_raw(motor_id, degrees)
            for motor_id, degrees in phase_positions.items()
        }
        if not trial.wait_until_raw_positions(
            raw_targets,
            tolerance=96,
            timeout=4.0,
            recorder=recorder,
        ):
            raise RuntimeError("distal-only phase staggering did not settle")
        if self.recalibrate_phase_pose:
            pose = self.planner.nominal_motor_degrees
            for leg in self.planner.TRIPOD_B:
                pose[11 + leg] += self.config.tripod_b_phase_offset_degrees
            self.planner.reset(phase=self.phase, motor_degrees=pose)
        trial.controller.set_all_mode(Actuator.OperatingMode.VELOCITY)
        trial.controller.set_velocities(
            {motor_id: 0 for motor_id in Actuator.Index.LOWER}
        )
        self._filtered_velocity.fill(0.0)
        self._active = True
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

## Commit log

2024-05-22 refactor: main.py divided to actuator & controller
2024-05-22 feat: key input threading
2024-05-23 feat: print help by pressing h
2024-05-23 feat: print info
2024-05-23 refactor: re-aligned print
2024-05-24 feat: motor velocity control
2024-05-24 test: I broked my motors...damn..
    [actuator.py, controller.py]
2024-05-24 fix: port variable name corrupted
    [controller.py]
2024-05-24 feat: added torque enable
2024-05-24 test: test torque control
2024-05-24 fix: port handler name fixed
    [controller.py]
2024-05-24 feat: torque disable added & cli command added
2024-05-24 feat: expanded actuator index
2024-05-24 chore: renamed directory & added papers about the current project
2024-05-24 fix: git merge corrupt
    [actuator.py]
2024-05-24 fix: changed input of position as int
    [controller.py]
2024-05-24 fix: cli error & drive position modified
    [walk.py]
2024-05-24 fix: fixed velocity control address
    [actuator.py, controller.py]
2024-05-27 test: fixed to cli test environment
    [walk.py]
2024-05-28 fix: turn async deleted
    [walk.py]
2024-05-28 fix: pause usiing status:
    [walk.py]
2024-05-28 fix: actuator position offset modified
    [controller.py]
2024-06-01 feat: get torque added in cli
2024-06-03 feat: torque controll added in cli
2024-06-04 refactor: deleted devices
2024-06-06 fix: walk class added
    [walk.py]
2024-06-06 fix: file relative link fixed
    [controller.py, walk.py]
2024-06-07 fix: enable / disable torque uses set all torque
    [controller.py]
2024-06-08 fix: deleted unnecessary code in walk.py
    [walk.py]
2024-06-10 feat: added actuator controller to cli
2024-07-03 chore: added blueprint of Arc-Shaped Wheel used in SCONEv2, and Since I'm a somophore in highschool, I could not have enough time for this project good luck :)
2026-08-30 feat: added MuJoCo Residual RL
    [ARC_SHAPED_WHEEL.stl, BODY.stl, BODY_ACTUATOR.stl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]
2026-08-30 feat: update RL and archive compressed media
    [SCONEv1.obj, SCONEv2.obj]
2026-08-30 refactor: refactored
    [ARC_SHAPED_WHEEL.stl, BODY.stl, BODY_ACTUATOR.stl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]
2026-08-31 docs: align guides with current repository
2026-08-31 fix: align gait tuning with PPO replay dynamics
    Tune Non-RL support points, stride limits, IK backoff, and diagnostics. Preserve the actuator dynamics and hardcoded reference expected by legacy PPO checkpoints. Consolidate RL dependencies and update the development and performance documentation.
2026-09-01 docs(icra): rewrite the manuscript around the controller that produced the results
    Section IV described SconeGait's phase gate and the PPO speed blend, but the
    benchmark behind every number in Section VI runs RollGait: a velocity-mode
    superposition of continuous arc rotation on the differentiated walking
    reference. bounded-scone (SconeGait) appears in no reported trial, and
    beta(0.18) = 1 makes the residual policy inactive at the operating point of
    every table.
    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
2026-09-01 feat(rl): actuator fidelity, canonical body frame, and a redesigned walking PPO
    Everything here is backed by loading model.xml in MuJoCo and measuring. The
    numbers are in docs/18-actuator-model-and-frame-convention.md.
    Actuator model. The dcmotor nominal triples match the ROBOTIS e-Manual at 12 V,
    but the derived stall current sits 12-28 percent below the datasheet because the
    sheet's stall torque is post-gearbox; the implied gear and motor efficiency is
    0.72-0.88, so the electrical estimate reads low and the efficiency=1.0 default in
    quasi_static_pivot_torque is optimistic. The larger gap was that all 18 joints
    carried no armature. Reflected rotor inertia J_rot*N^2 is 0.22x, 1.06x and 2.50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
    [tripod_gait.py]
2026-09-02 feat(rl): make walk_v2 trainable over SSH through the existing launcher
    walk_v2's argument layout now matches walk_learn exactly, so
    inquiry.build_training_arguments drives either trainer and a detached remote run
    keeps the same pause/resume contract:
    runs/<name>/checkpoints/scone_walk_v2_<steps>_steps.zip
    runs/<name>/resume.checkpoint run-relative pointer the launcher reads
    runs/<name>/train.log | train.pid | train.state
    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
2026-09-02 fix(model): drop the double-counted gearbox friction and re-damp the PD loop
    Audit of the actuator edit from the previous commit, benched against the
    e-Manual rather than argued from the datasheet table.
    The damping and frictionloss values were wrong and are removed. The e-Manual
    stall torque and no-load speed are measured at the output shaft of the assembled
    actuator, so gearbox and motor loss already lives inside the nominal triple; the
    model reaches zero net torque exactly at the rated no-load speed. Adding explicit
    friction on top double-counted it and cost 3.0 to 3.7 percent of no-load speed.
    With the friction gone both datasheet endpoints are reproduced to 0.0 percent.
    armature stays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
2026-09-02 docs(rl): cross-check the actuator model against published Dynamixel MuJoCo models
    Compared src/assets/model.xml with the MuJoCo Menagerie robotis_op3 model, which
    drives twenty XM430-W350 units, the same actuator as our middle joints. Google
    DeepMind and ROBOTIS ship identical values, so that is one data point rather than
    two. Rather than cite it, benched it: both parameterisations on the same
    single-joint rig.
    stall no-load
    datasheet 4.100 N m 4.817 rad/s
    SCONE (dcmotor) 4.100 +0.0% 4.817 -0.0%
    Menagerie OP3 (position) 5.000 +22.0% 4.581 -4.9%
    The finding that matters supports yesterday's correction. Menagerie's
    damping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
2026-09-02 docs(rl): add Open Duck Mini v2 as a second sim-to-real reference
    Checked the claim that Open Duck Mini uses Dynamixel. Its v2 MJCF names the
    default class STS3215 and the docs reference Feetech STS3215 specs, so v2 is
    Feetech. The v1 (mini_BDX) servo could not be verified: the BOM lives in an
    external Google Sheet, so a small Dynamixel there is not ruled out. Recorded
    both the finding and the limit of it.
    The brand turned out to be the less interesting part. Open Duck Mini v2 trains
    in MuJoCo and deploys to a Raspberry Pi Zero 2W, which is the sim-to-real
    reference with published numbers that was missing before, and it confirms the
    damping finding a third time:
    (3.23 - 0.068) / 0.56 = 5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
2026-09-02 feat(model): model gear backlash, and split the Dynamixel work into a package
    Backlash. The e-Manual publishes it (20 arcmin on the MX-28AT, 15 on the XM430)
    and at the 0.1225 m arc radius 15 arcmin is 0.53 mm of contact position, which
    is not negligible for a paper about edge engagement. Modelled the way Open Duck
    Mini v2 does: a limited free joint on the same body and axis as the driven
    joint, so the body angle is the sum and the actuator drives only the first. No
    extra bodies, nq 25 -> 43.
    Two things had to be right for it to mean anything:
    - MuJoCo's default joint limit is soft enough that 0.5 N m pushed 38-43 arcmin
    past a 7.5 arcmin stop, five times the play the datasheet allows. W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
2026-09-02 fix(sim): measure whether each actuator setting earns its place, and correct a bad call
    Retracting a claim first. The previous commit reported "net new failures: zero"
    after diagnosing a stair-climber failure as a test that advances only 1.5 s
    against a controller that allows itself 4.0 s. Half of that was right and the
    conclusion was wrong: the same hard-coded window lives in
    src/simulation/stair_benchmark.py, which is the benchmark itself, not a test.
    Run directly, stairs-1 reaches the top on the pre-armature model and raises a
    common-phase acquisition error with armature. Fixing only the test hid a real
    failure.
    It is still not a capability loss. Settling went from under 1.5 s to about
    2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
2026-09-02 feat: modified actuator settings & made ppo v2
2026-09-02 fix(benchmark): restore tire geometry lookup
2026-09-02 fix(rl): open walk v2 viewers across replay flows
2026-09-06 feat(rl): add walk_v3, a residual trainer with no speed ceiling
    walk_v2 could not beat its own zero-residual scaffold, so v3 returns to v1's
    residual structure and fixes what was actually wrong with it: the command was
    several times what the scaffold could deliver.
    - Derive stride, lift and cadence from measured (achieved, command) tables
    instead of a single gain. Speed is not linear in stride -- it climbs to
    about 40 degrees, plateaus, then climbs again -- and one gain over-delivered
    by 152% at 0.10 m/s while under-delivering at 0.30. Zero-residual tracking
    after calibration is 100-104% from 0.05 to 0.30 m/s.
    - One-sided speed reward: full credit at the command, no penalty above it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
2026-09-06 feat(rl): walk with a leg gone -- fault-adaptive scaffold and a fail-safe PPO
    The right rear leg (L5) has failed on the physical robot. An alternating
    tripod cannot survive that: groups (1,4,5) and (2,3,6) each carry the robot
    alone, so losing one leg leaves its group a two-foot line and the machine tips
    about it twice a cycle. A residual policy adds to its reference, so no amount
    of training rescues a scaffold that is statically impossible. This changes the
    scaffold, then the objective.
    Leg loss in the model (src/simulation/core/model.py)
    - amputate_legs(legs, mode) with two modes. "detached" removes the leg's mass,
    collision and drawing (4.161 -> 3.611 kg for one leg, 13.2%); "limp" kee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
2026-09-06 fix(rl): align walk_failsafe's CLI with the other three trainers
    Two argument-layout defects, both found by feeding the launcher's own
    generated argv into each trainer's parser:
    - The subparser dest was "command", which check and enjoy silently overwrite
    with their --command velocity vector. Anything reading args.command to learn
    the subcommand got [vx, vy, yaw] instead. Renamed to command_name, matching
    walk, walk_v2 and walk_v3.
    - --output, --tensorboard-log, --resume and the enjoy checkpoint were plain
    strings where the other trainers use Path.
    Adds the regression test that found them: every registered task's
    build_training_arguments output is parsed by that task's own build_par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
2026-09-06 fix(rl): clamp a replay command to the fail-safe trainer's own range
    The shared replay viewer, the joystick and the launcher all carry walk_learn's
    command scale of [0.50, 0.25, 0.80]. walk_failsafe normalises by
    [0.14, 0.06, 0.30], measured from what a five-legged wave scaffold can
    actually deliver, so the viewer's own default command of 0.25 m/s is already
    1.8x this scale.
    Passed through unclamped it reached the policy as a normalised command of
    [3.57, 4.17, 2.67] -- several times outside anything seen in training, with
    nothing in the output to say so. The constructor now clamps and prints one
    line naming both values.
    Claude-Session: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
2026-09-06 test(rl): prove the fail-safe objective is climbable before spending a run
    The promotion gate decides whether a training run is worth continuing, so two
    things about it have to hold, and neither was covered.
    - It has to be repeatable. Both evaluations are seeded and deterministic, and
    the baseline now has to reproduce exactly.
    - It has to be sensitive to a genuinely better controller. A hand-written
    residual that only damps yaw rate -- the scaffold's known defect once a leg
    is lost -- scores 0.913 against the scaffold's 0.795 and improves the worst
    case too, so a policy that beats the baseline demonstrably exists. walk_v3
    spent 100M steps discovering that its own objective had no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
2026-09-06 fix(rl): stop charging the fail-safe policy for a heading it was not asked to hold
    The heading target integrates the commanded yaw rate, inherited from v1. Any
    shortfall in the achieved rate accumulates an angle the policy has no way to
    recover, because it was asked for a rate and charged for a position. This is
    the defect docs/21 section 12 records in walk_v2; the bounded cost here made
    it milder, not absent.
    Measured on the bare scaffold over 12 s:
    two legs lost, yaw 0.30 -> 0.59 rad of debt, 98% of the cap, -0.235/s
    one leg lost, forward -> 0.66 rad, -0.267/s
    The first is an unrecoverable debt from tracking short. The second is the veer
    this trainer exists to correct, and has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
2026-09-06 fix(rl): make a mistyped leg number a usage error, and cover termination
    --failed-legs accepted any integer and the set-level check ran after argparse
    had finished, so "check --failed-legs 7" printed a traceback where every other
    bad argument prints one line. It is now an argparse type.
    Also covers the termination path, which nothing reaches on its own: a bounded
    residual on a statically stable wave scaffold does not fall over even at full
    adversarial amplitude, so a sign error in the fall check would never surface.
    Forced with a 0.5 degree tilt threshold, the charge matches the formula to six
    places and is strictly worse than the worst survivable episode.
    Verified by hand across every CLI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
2026-09-06 fix(rl): keep the support and heading costs from going flat where the robot lives
    Enumerating all fifteen two-leg faults: only the three diagonal pairs are
    marginally stable at -0.0000, and the other twelve leave the scaffold between
    -0.09 and -0.21 m even after the shift search spends its whole 26-36 degree
    budget. The trainer samples two-leg faults in a fifth of its episodes.
    The support cost clipped at -target, so every one of those twelve was a flat
    0.60/s charge with no gradient: the policy was punished for a state it was
    given no reason to leave. The heading cost had the same defect past 0.60 rad,
    which the measured leg-loss veer reaches in twelve seconds.
    Both now saturate softly, x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
2026-09-06 fix(rl): score tracking on a filtered velocity, not the gait cycle's ripple
    A 400k-step run showed the failure this was written to avoid: reward/tracking
    fell monotonically, +0.985 -> +0.885 -> +0.830 per second, while the penalties
    fell faster and the episode return rose. The policy was improving its score by
    not doing the task. Numerics were healthy throughout -- approx_kl 0.012-0.040,
    never inf, entropy and std stable -- so this was the objective, not the
    optimiser.
    The cause is that tracking read the instantaneous body velocity. A walking
    body surges and rocks every cycle: measured on the bare scaffold, vx has a
    standard deviation of 0.039-0.064 m/s and yaw rate 0.130-0.235 rad/s, both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
2026-09-06 fix(rl): score the promotion gate on commands the curriculum actually trains
    The gate used a fixed command grid. On the easy curriculum, whose range is
    0.06 m/s forward only, that grid asked for 0.12 m/s and a 0.25 rad/s turn --
    neither ever sampled during training. Measured across one run's checkpoints,
    the worst-case score it reported was 0.470 where the same policy scored 1.235
    inside its own range, so the promotion criterion was being decided by motion
    the policy was never taught, and improvement within its range could not show
    up in the number that gates it.
    Evaluation commands are now derived from the curriculum: half and full
    forward speed always, plus a turn and a lateral command wh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
2026-10-08 get hyped for the new project 🚀
    [0619.stp, A01_before_print_redesign.f3d, ARC_SHAPED_WHEEL.stl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]
